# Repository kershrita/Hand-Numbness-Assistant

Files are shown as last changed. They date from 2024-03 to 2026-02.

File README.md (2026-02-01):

# Hand Numbness Assistant 🖐️🌡️





An assistive wearable device designed to help people with hand numbness safely interact with their environment by detecting object temperatures before physical contact.

---

## Table of Contents

- [Overview](#overview)
- [Problem Statement](#problem-statement)
- [Features](#features)
- [Hardware Requirements](#hardware-requirements)
- [Software Dependencies](#software-dependencies)
- [System Architecture](#system-architecture)
- [Circuit Connections](#circuit-connections)
- [Installation](#installation)
- [Usage](#usage)
- [3D Printed Parts](#3d-printed-parts)
- [Configuration](#configuration)
- [Troubleshooting](#troubleshooting)
- [Contributing](#contributing)
- [License](#license)
- [Contact](#contact)

---

## Overview

The Hand Numbness Assistant is an Arduino-based wearable system that uses the **MLX90614 Non-Contact IR Temperature Sensor** to detect object temperatures without physical contact. This device helps individuals who suffer from conditions like peripheral neuropathy, diabetes-related numbness, or other sensory impairments by alerting them when an object is too hot or cold to safely touch.

---

## Problem Statement

People with hand numbness face a significant daily challenge: they cannot feel temperature differences through touch. This puts them at risk of:

- **Burns** from hot surfaces, liquids, or objects
- **Frostbite** from extremely cold items
- **Injuries** from unknowingly handling dangerous temperature objects

This project provides a practical, affordable solution by offering **pre-contact temperature sensing** with real-time alerts.

---

## Features

- **Non-Contact Temperature Sensing**: Measures object temperature without touching it
- **Wireless Communication**: Uses nRF24L01 radio modules for transmitter-receiver communication
- **Real-time Alerts**: Audible buzzer and LED indicators for temperature warnings
- **Wearable Vibration Alert**: Receiver unit can be worn on the wrist for haptic feedback
- **Configurable Threshold**: Adjustable temperature threshold (default: 40°C)
- **Emissivity Correction**: Accurate readings across different material types
- **Low Power Consumption**: Suitable for portable, battery-powered operation
- **3D Printable Enclosure**: Custom-designed cases for easy assembly

---

## Hardware Requirements

### Transmitter Unit (Temperature Sensing Module)

| Component | Quantity | Description |
|---|---|---|
| Arduino Nano/Uno | 1 | Main microcontroller |
| MLX90614 | 1 | Non-contact IR temperature sensor |
| nRF24L01 | 1 | 2.4GHz wireless transceiver module |
| Buzzer | 1 | Audio alert indicator |
| Red LED | 1 | Visual warning indicator |
| 220Ω Resistor | 1 | LED current limiting |
| Capacitor 10µF | 1 | nRF24L01 power stabilization |
| Wires | - | Jumper wires for connections |
| Power Supply | 1 | 5V battery pack or USB power |

### Receiver Unit (Wearable Alert Module)

| Component | Quantity | Description |
|---|---|---|
| Arduino Nano/Uno | 1 | Main microcontroller |
| nRF24L01 | 1 | 2.4GHz wireless transceiver module |
| Vibration Motor | 1 | Haptic feedback alert |
| Capacitor 10µF | 1 | nRF24L01 power stabilization |
| Wires | - | Jumper wires for connections |
| Power Supply | 1 | 3.7V LiPo battery or USB power |

---

## Software Dependencies

### Arduino Libraries Required

1. **RF24** - For nRF24L01 wireless communication
   - Install via Arduino Library Manager: `RF24 by TMRh20`

2. **DFRobot_MLX90614** - For MLX90614 temperature sensor
   - Install via Arduino Library Manager or [DFRobot GitHub](https://github.com/DFRobot/DFRobot_MLX90614)

3. **Adafruit GFX Library** - Graphics library (included in `/libs`)

4. **Adafruit SSD1306** - OLED display support (included in `/libs`)

5. **SPI** - Built-in Arduino library

---

## System Architecture

```
┌─────────────────────────────────────────────────────────────────┐
│                    TRANSMITTER UNIT                             │
│  ┌─────────────┐    ┌─────────────┐    ┌─────────────┐         │
│  │  MLX90614   │───▶│   Arduino   │───▶│  nRF24L01   │────┐    │
│  │ Temp Sensor │    │   Nano/Uno  │    │   Radio     │    │    │
│  └─────────────┘    └──────┬──────┘    └─────────────┘    │    │
│                            │                               │    │
│                     ┌──────┴──────┐                        │    │
│                     │ Buzzer + LED│                        │    │
│                     └─────────────┘                        │    │
└────────────────────────────────────────────────────────────┼────┘
                                                             │
                         Wireless Communication (2.4GHz)     │
                                                             │
┌────────────────────────────────────────────────────────────┼────┐
│                     RECEIVER UNIT                          │    │
│  ┌─────────────┐    ┌─────────────┐    ┌─────────────┐    │    │
│  │  Vibration  │◀───│   Arduino   │◀───│  nRF24L01   │◀───┘    │
│  │    Motor    │    │   Nano/Uno  │    │   Radio     │         │
│  └─────────────┘    └─────────────┘    └─────────────┘         │
└─────────────────────────────────────────────────────────────────┘
```

---

## Circuit Connections

### Transmitter Unit Wiring

#### MLX90614 to Arduino
| MLX90614 Pin | Arduino Pin |
|---|---|
| VCC | 5V |
| GND | GND |
| SDA | A4 |
| SCL | A5 |

#### nRF24L01 to Arduino
| nRF24L01 Pin | Arduino Pin |
|---|---|
| VCC | 3.3V |
| GND | GND |
| CE | D10 |
| CSN | D9 |
| SCK | D13 |
| MOSI | D11 |
| MISO | D12 |

#### Alert Components
| Component | Arduino Pin |
|---|---|
| Buzzer (+) / LED Anode | D2 (wired in parallel, LED via 220Ω resistor) |

> **Note**: The buzzer and LED share the same output pin (D2) and are wired in parallel. This allows both alert mechanisms to activate simultaneously when the temperature threshold is exceeded.

### Receiver Unit Wiring

#### nRF24L01 to Arduino
| nRF24L01 Pin | Arduino Pin |
|---|---|
| VCC | 3.3V |
| GND | GND |
| CE | D10 |
| CSN | D9 |
| SCK | D13 |
| MOSI | D11 |
| MISO | D12 |

#### Vibration Motor
| Component | Arduino Pin |
|---|---|
| Vibration Motor (+) | D2 |

> **Note**: Add a 10µF capacitor between VCC and GND of nRF24L01 for power stability.

---

## Installation

### Step 1: Install Arduino IDE

Download and install the [Arduino IDE](https://www.arduino.cc/en/software) (version 1.8.x or 2.x).

### Step 2: Install Required Libraries

1. Open Arduino IDE
2. Go to **Sketch** → **Include Library** → **Manage Libraries**
3. Search and install:
   - `RF24` by TMRh20
   - `DFRobot_MLX90614`

4. For the included libraries in `/libs`:
   - Extract `Adafruit-GFX-Library-master.zip`
   - Extract `Adafruit_SSD1306-master.zip`
   - Copy to your Arduino libraries folder (typically `Documents/Arduino/libraries/`)

### Step 3: Clone the Repository

```bash
git clone https://github.com/kershrita/Hand-Numbness-Assistant.git
cd Hand-Numbness-Assistant
```

### Step 4: Upload Transmitter Code

1. Open `transmitter/transmitter.ino` in Arduino IDE
2. Select your board: **Tools** → **Board** → **Arduino Nano/Uno**
3. Select the correct COM port
4. Click **Upload**

### Step 5: Upload Receiver Code

1. Open `receiver/receiver.ino` in Arduino IDE
2. Select your board: **Tools** → **Board** → **Arduino Nano/Uno**
3. Select the correct COM port
4. Click **Upload**

---

## Usage

1. **Power On**: Connect both transmitter and receiver units to their power sources.

2. **Initial Connection**: Wait for the serial monitor to display "Connected!" (receiver) and confirm the sensor is initialized (transmitter).

3. **Point and Measure**: 
   - Point the transmitter unit's sensor toward the object you want to measure
   - Hold at a distance of 2-5 cm for optimal accuracy

4. **Alert Interpretation**:
   - **No alert**: Object temperature is below the threshold (safe to touch)
   - **Buzzer + LED + Vibration**: Object temperature exceeds the threshold (DANGER - do not touch!)

5. **Serial Monitor**: Connect to the transmitter via USB to view real-time temperature readings:
   ```
   Ambient celsius : 24.5 C
   Object celsius : 65.3 C
   ```

---

## 3D Printed Parts

Custom enclosures are provided in the `3d parts/` directory:

| File | Description |
|---|---|
| `core-heat-box.stl` | Transmitter unit main body |
| `core-heat-cover.stl` | Transmitter unit cover |
| `core-pi-box.stl` | Receiver unit main body |
| `core-pi-cover.stl` | Receiver unit cover |

### Print Settings (Recommended)

- **Material**: PLA or PETG
- **Layer Height**: 0.2mm
- **Infill**: 20%
- **Supports**: Not required

---

## Configuration

### Adjusting Temperature Threshold

Edit the threshold value in `transmitter/transmitter.ino`:

```cpp
#define TEMPERATURE_THRESHOLD 40.0  // Change this value (in Celsius)
```

### Emissivity Correction

Different materials have different emissivity values. Adjust in `transmitter/transmitter.ino`:

```cpp
sensor.setEmissivityCorrectionCoefficient(0.98);  // Default value
```

Refer to `emissivity values table.xlsx` for common material emissivity values.

| Material | Emissivity |
|---|---|
| Human Skin | 0.98 |
| Water | 0.96 |
| Metal (polished) | 0.05-0.10 |
| Plastic | 0.85-0.95 |
| Wood | 0.80-0.90 |

---

## Troubleshooting

### Common Issues and Solutions

| Issue | Possible Cause | Solution |
|---|---|---|
| "Not Connected!" message | Radio not properly connected | Check nRF24L01 wiring and add 10µF capacitor |
| No temperature readings | Sensor connection issue | Verify MLX90614 I2C connections (SDA/SCL) |
| Inaccurate readings | Wrong emissivity value | Adjust emissivity for the material being measured |
| No wireless communication | Address mismatch | Ensure both units use the same address (`"12345"`) |
| Receiver not vibrating | Motor connection issue | Check pin D2 connection and motor polarity |

### Serial Monitor Debugging

1. Open Arduino IDE Serial Monitor (9600 baud)
2. Monitor transmitter output for temperature readings
3. Monitor receiver output for received signals (`true`/`false`)

---

## Contributing

Contributions are welcome! Please read our [Contributing Guidelines](CONTRIBUTING.md) before submitting a pull request.

### Ways to Contribute

- Report bugs and issues
- Suggest new features
- Improve documentation
- Submit code improvements
- Share improved 3D print designs

---

## License

This project is licensed under the MIT License - see the [LICENSE](LICENSE) file for details.

---

## Contact

**Ashraf Abdulkhaliq**

- GitHub: [@kershrita](https://github.com/kershrita)

---

<p align="center">
  Made with ❤️ for accessibility and assistive technology
</p>

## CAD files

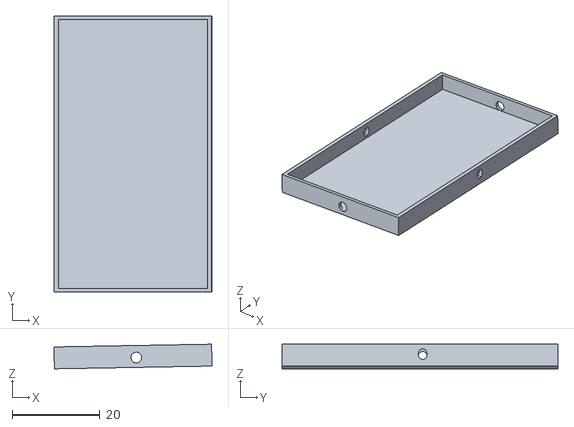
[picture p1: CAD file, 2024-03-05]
3d parts/core-pi-cover.stl
36.1 x 63.0 x 5.63

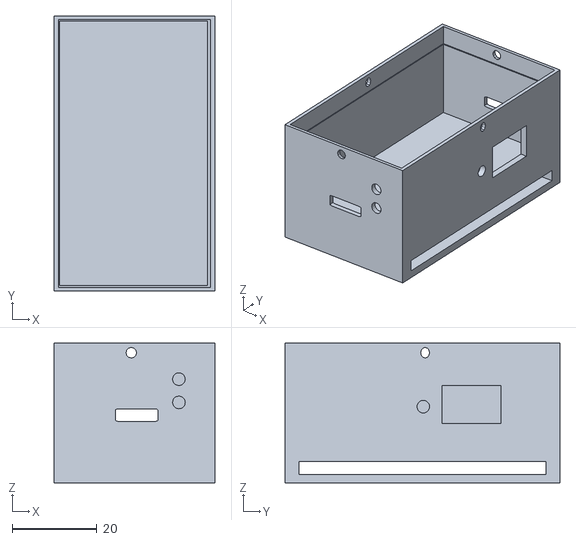
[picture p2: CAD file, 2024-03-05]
3d parts/core-pi-box.stl
38.0 x 65.0 x 33.0

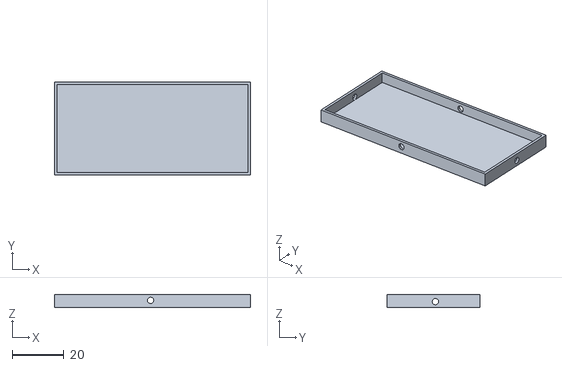
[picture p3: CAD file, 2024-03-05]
3d parts/core-heat-cover.stl
76.0 x 36.0 x 5.00

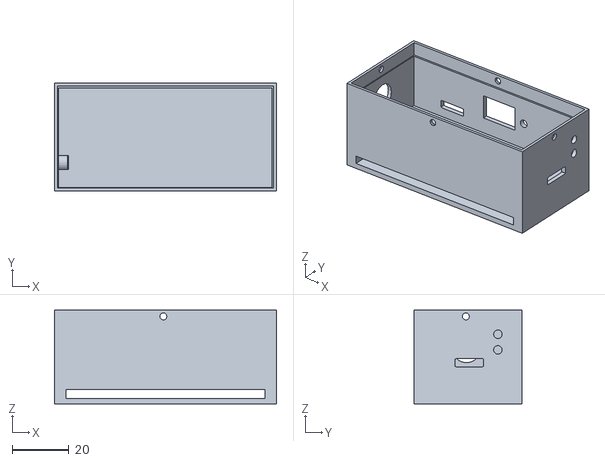
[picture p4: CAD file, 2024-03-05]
3d parts/core-heat-box.stl
78.0 x 38.0 x 33.0

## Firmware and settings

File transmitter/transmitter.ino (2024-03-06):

#include <SPI.h>
#include <nRF24L01.h>
#include <RF24.h>
#include <DFRobot_MLX90614.h>

// Threshold Temperature
#define TEMPERATURE_THRESHOLD 40.0

DFRobot_MLX90614_I2C sensor;   // instantiate an object to drive our sensor

RF24 radio(10, 9); // CE, CSN
const byte address[6] = "12345";
bool vib = false;

void setup() {
  Serial.begin(9600);

  pinMode(2, OUTPUT);
  
  while(!radio.begin()){
    Serial.print("Not Connected! ...\n");
    delay(2000);
  }
  
  // initialize the sensor
  while( NO_ERR != sensor.begin() ){
    Serial.println("Communication with device failed, please check connection");
    delay(2000);
  }

  radio.openWritingPipe(address);
  radio.setPALevel(RF24_PA_MIN);
  radio.stopListening();

  sensor.setEmissivityCorrectionCoefficient(0.98);

  sensor.enterSleepMode();
  delay(50);
  sensor.enterSleepMode(false);
  delay(200);
}

void loop() {

  // get ambient temperature, unit is Celsius
  float ambientTemp = sensor.getAmbientTempCelsius();

  // get temperature of object 1, unit is Celsius
  float objectTemp = sensor.getObjectTempCelsius();

  // print measured data in Celsius
  Serial.print("Ambient celsius : "); Serial.print(ambientTemp); Serial.println(" C");
  Serial.print("Object celsius : ");  Serial.print(objectTemp);  Serial.println(" C");

  // Update LEDs and Buzzer based on temperature
  if (objectTemp > TEMPERATURE_THRESHOLD) {
    digitalWrite(2, HIGH);   // Turn on Red LED and Buzzer
    vib = true;
    radio.write(&vib, sizeof(vib)); // send the message
    
  } else {
    digitalWrite(2, LOW);    // Turn off Red LED
    vib = false;
    radio.write(&vib, sizeof(vib)); // send the message
  }
  
  delay(1000);
}

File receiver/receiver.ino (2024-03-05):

#include <SPI.h>
#include <nRF24L01.h>
#include <RF24.h>

RF24 radio(10, 9); // CE, CSN

const byte address[6] = "12345";

void setup() {
  Serial.begin(9600);
  
  while(!radio.begin()){
    Serial.print("Not Connected! ...\n");
    delay(1000);
  }

  Serial.print("Connected! ...\n");
  delay(500);

  pinMode(2, OUTPUT);
  
  radio.openReadingPipe(0, address);
  radio.setPALevel(RF24_PA_MIN);
  radio.startListening();
}

void loop() {
  bool tx;
  if (radio.available()) {
    radio.read(&tx, sizeof(tx));
    Serial.println(tx);

    if(tx)
      digitalWrite(2, HIGH);
    else
      digitalWrite(2, LOW);
  }
}

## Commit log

2024-03-05 add emissivity table for the objects
    [emissivity values table.xlsx]
2024-03-05 add 3d parts
    [core-heat-box.stl, core-heat-cover.stl, core-pi-box.stl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]
2026-02-01 Enhance project documentation and contributor onboarding (#1)
    * Initial plan
    * Enhance project presentation with comprehensive README and CONTRIBUTING guide
    * Clarify parallel wiring for buzzer and LED on shared pin D2
    * Remove emojis and update section headers in CONTRIBUTING.md
    * Update section headers in README.md
    ---------

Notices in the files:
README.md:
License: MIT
